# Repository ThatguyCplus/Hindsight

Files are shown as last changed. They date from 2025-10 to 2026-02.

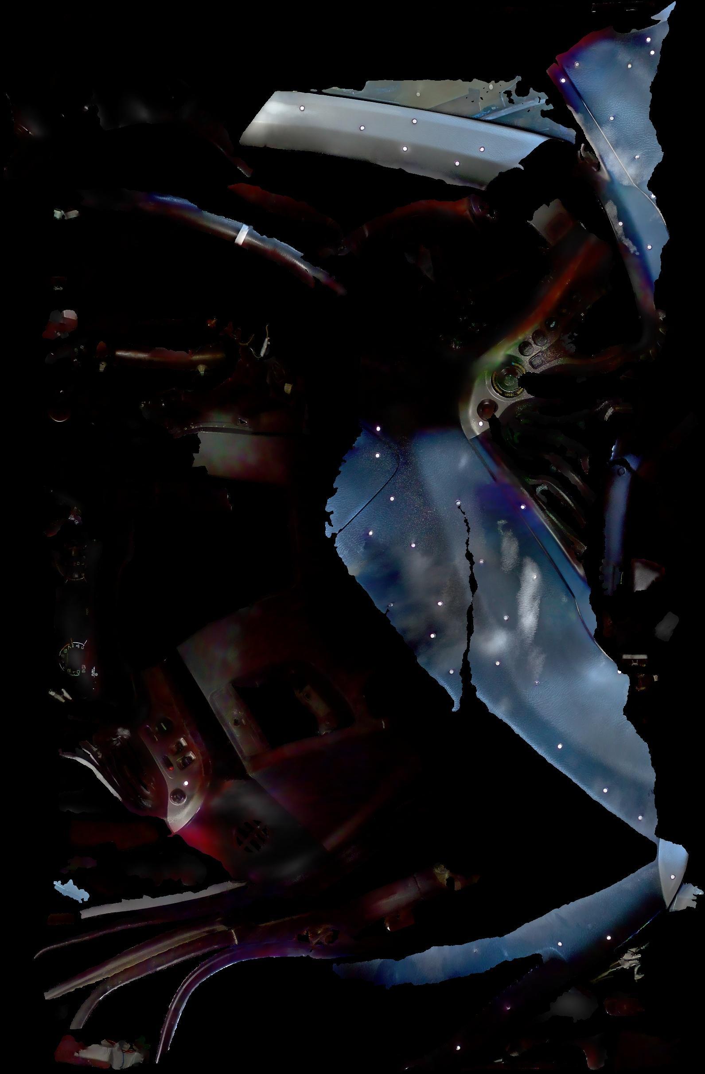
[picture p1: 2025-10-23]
Honda Insight 2002 3D scans/Dashboard/dashboardholesfilled.jpg

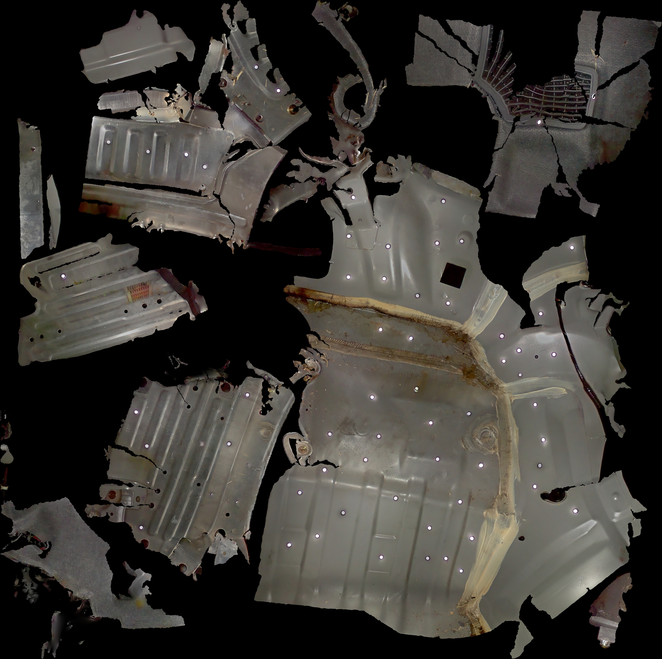
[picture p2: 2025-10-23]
Honda Insight 2002 3D scans/Insight behind trunk emtpy space/trunkemptyspace2002hondainsight2002scan.jpg

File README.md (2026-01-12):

# Hindsight

**Senior Design Project**: Build a safe, paraplegic-focused electronic throttle and brake control system for a 2002 Honda Insight. We’re designing the driver interface, selecting and validating sensors and actuators, and integrating everything on the vehicle for a live demo that aligns with SAE safety principles and ADA usability goals.usability goals.

## Project Overview

Hindsight retrofits a 2002 Honda Insight with an electronic throttle-and-brake assist system so paraplegic drivers can control the car using alternative hand inputs—without taking away the original pedals for other family members. It converts pedal commands into a safe, intuitive electronic interface while prioritizing fail-safes, manual override, and everyday usability for all drivers.

## Repository Structure

### 📂 Brakes/
Contains the brake control system implementation using a Tesla Gen2 iBooster unit.

<!-- TODO: Add image of iBooster installation in vehicle brake system -->
<!-- <img width="800" alt="iBooster Installation" src="path/to/ibooster-installation.jpg" /> -->


- **`Iboostercontrolnotworkingjustthrottlepostion/`**
  - `Iboostercontrolnotworkingjustthrottlepostion.ino` - Tesla Gen2 iBooster CAN bus controller
    - Controls brake system via CAN bus (500 kbps)
    - Uses MCP2515 CAN transceiver with Arduino Mega
    - Implements serial commands for brake control (apply/release/hold)
    - Monitors brake rod position and status via 0x39D CAN messages

https://github.com/user-attachments/assets/6a48c70b-f8df-4b89-a8cc-46501188acb3

- **`Adaptor CAD`**

  

<!-- TODO: Add image of brake control CAN bus setup or wiring diagram -->
<!-- <img width="800" alt="CAN Bus Wiring" src="path/to/can-bus-wiring.jpg" /> -->

### 📂 Throttle/
Complete throttle control system with Arduino firmware and mechanical CAD designs.

<!-- TODO: Add image of throttle mechanism with motor actuator and sensor -->
<!-- <img width="800" alt="Throttle Actuator System" src="path/to/throttle-actuator.jpg" /> -->
https://github.com/user-attachments/assets/ef57e486-5c61-4791-867c-b409ffe35655

#### **Throttle Arduino Sketches/**
Arduino firmware for throttle control and sensor testing:

- **`as5048atestingscketches/livereadout/`**
  - `livereadout.ino` - AS5048A magnetic angle sensor testing with motor control
    - Logs angle measurements at 100 Hz during motor cycles
    - Tests IBT-2/BTS7960 motor driver with forward/reverse/coast sequences
    - CSV output format for data analysis

- **`initialjoystick/`**
  - `initialjoystick.ino` - Joystick-based throttle control interface
    - Maps joystick input to motor control with exponential response curve
    - Implements hard-stop (electronic brake) with current monitoring
    - Safety features: dead zone, current limits, relay control

- **`Intialtestingcruisecontrolhindsight/`**
  - `Intialtestingcruisecontrolhindsight.ino` - Cruise control functionality testing
    - Initial implementation for throttle position holding

#### **Throttle CAD work/**
Mechanical design files for sensor mounting and bracket systems:



- Holds Diametric Magnet for sensor
  


- Sensor support bracket designs (v2, v3, v5)
- Files in multiple formats: `.SLDPRT` (SolidWorks), `.STL`, `.3MF`
- Key components:
  - `SensorSupportbracketv5covered.STL/.3MF` - Latest sensor mount design
  - `NoarmCC.SLDPRT` - Cruise control bracket without arm
  - `IntialCCbracket.SLDPRT` - Initial cruise control bracket concept

<!-- TODO: Add rendered image of CAD bracket designs or 3D printed parts -->
<!-- <img width="800" alt="Sensor Support Bracket v5" src="path/to/bracket-v5.jpg" /> -->
<!-- <img width="800" alt="3D Printed Bracket Installed" src="path/to/bracket-installed.jpg" /> -->

### 📂 Honda Insight 2002 3D scans/
3D scanned models of vehicle interior components used for design and integration.

<!-- TODO: Add example 3D scan visualization showing brake system context -->
<!-- <img width="800" alt="3D Scan - Brake System Context" src="path/to/brake-scan-view.jpg" /> -->



- **Brakes/**
  - iBooster context scans with corrected axis
  - Full detail scans of brake system mounting area
  - Formats: `.obj`, `.mtl`, `.SLDPRT`



- **Dashboard/**
  - Dashboard assembly with left interior pillar trim
  - Used for HMI (Human-Machine Interface) placement and integration



- **Footwell/**
  - Footwell area scans with trims installed
  - Critical for understanding pedal replacement constraints and mounting locations



- **Insight behind trunk empty space/**
  - Trunk empty space scans for component placement
  - Potential location for 12V battery relocation



- **UI (Between two seats parking brake area)/**
  - Area between seats where parking brake is located
  - Candidate location for alternative control interface placement
 


- **Leftwheelwellclutchmastercyclinderarea**
  - Wheel well area where the clutch master cylinder is on manual versions of the car
  - Candidate location for throttle actuator 

<!-- TODO: Add image of footwell area or dashboard showing integration points -->
<!-- <img width="800" alt="Footwell Integration" src="path/to/footwell-integration.jpg" /> -->
<!-- <img width="800" alt="UI Control Location" src="path/to/ui-location.jpg" /> -->

## Hardware Components

<!-- TODO: Add image of complete hardware setup or component layout diagram -->
<!-- <img width="800" alt="Hardware Component Layout" src="path/to/hardware-layout.jpg" /> -->

### Control Electronics
- **Arduino Mega 2560** - Primary microcontroller
- **MCP2515** - CAN bus controller (for brake system communication)
- **AS5048A** - Magnetic angle position sensor (for throttle position feedback)

### Actuators & Drivers
- **IBT-2 / BTS7960** - High-current H-bridge motor driver for throttle actuation
- **Tesla Gen2 iBooster** - Electronic brake booster (controlled via CAN bus)

### Sensors & Input
- **Analog Joystick** - Primary user input interface
- **Current Sense Resistors** - Motor current monitoring for safety

<!-- TODO: Add image of joystick interface or user control panel -->
<!-- <img width="800" alt="Joystick Control Interface" src="path/to/joystick-interface.jpg" /> -->

## Safety Features

- Current monitoring with automatic shutdown on overcurrent
- Hard-stop (electronic brake) functionality for rapid motor stopping
- CAN bus status monitoring for brake system feedback
- Exponential response curves for smooth control input
- Dead zone implementation to prevent unintended operation

## Software Requirements

- Arduino IDE (for firmware development)
- SolidWorks (for CAD file viewing/editing - `.SLDPRT` files)
- 3D viewer/printing software (for `.STL`, `.3MF` files)
- CAN bus analysis tools (optional, for debugging)

## Getting Started

1. **Hardware Setup**: Review the wiring diagrams in the Arduino sketch comments
2. **Firmware**: Upload the appropriate sketch to your Arduino Mega
3. **Calibration**: Adjust tuning parameters in the firmware (dead zones, current limits, etc.)
4. **Testing**: Use serial monitor for debugging and status monitoring

<!-- TODO: Add wiring diagram or connection schematic -->
<!-- <img width="800" alt="System Wiring Diagram" src="path/to/wiring-diagram.jpg" /> -->

## Serial Commands (Brake System)

When using the iBooster controller (`Iboostercontrolnotworkingjustthrottlepostion.ino`):

- `r` - Toggle raw CAN log
- `e` - Enable external request (take control)
- `d` - Disable external request (driver only, flow to zero-point)
- `b` - Apply brakes (flow_rate > zero point)
- `s` - Release brakes (flow_rate < zero point)
- `z` - Hold pressure (flow_rate = zero point)

## License

This project is licensed under the GNU General Public License v3.0 - see the [LICENSE](LICENSE) file for details.

## Contributing

This is a senior design project. For questions or contributions, please open an issue or contact the project maintainers.

---

## ⚠️ Important Disclaimer

**RESEARCH PROJECT ONLY — NOT FOR PRODUCTION USE**

This project is an academic research and development effort conducted as part of a senior design course. It is intended **solely for educational, research, and demonstration purposes**.

**NO WARRANTIES**: This software, hardware designs, and documentation are provided "AS IS" without warranty of any kind, express or implied, including but not limited to warranties of merchantability, fitness for a particular purpose, or safety for road use.

**NOT INTENDED FOR PUBLIC ROAD USE**: 
- This system modifies critical vehicle safety systems (throttle and brake controls)
- **DO NOT install, test, or operate this system on public roads**
- This system has NOT been certified, validated, or approved for real-world vehicle operation
- Any use of this system is at your own risk

**RESPONSIBILITY**: Anyone using, modifying, or building upon this project assumes full responsibility and liability for any damages, injuries, or legal consequences that may result. The authors and contributors are not responsible for any outcomes resulting from the use of this research project.

**FOR RESEARCH AND EDUCATIONAL PURPOSES ONLY.**

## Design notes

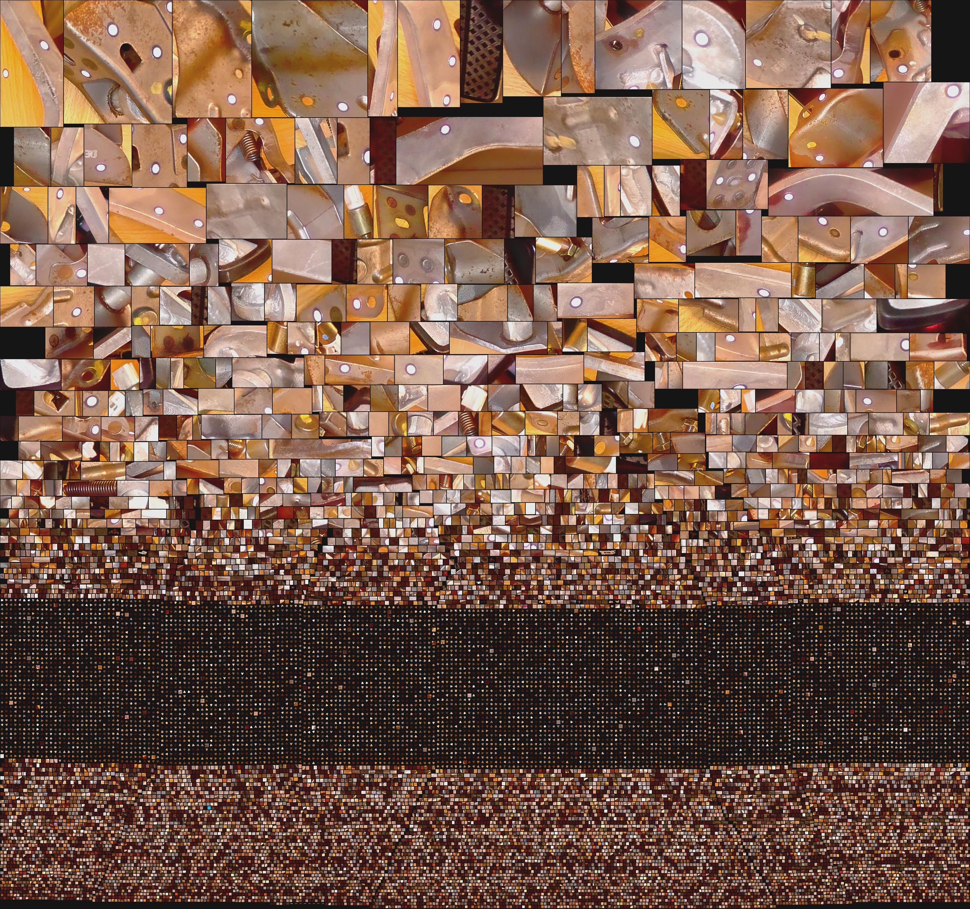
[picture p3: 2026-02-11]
Honda Insight 2002 3D scans/BrakePedalandbracket/optimizedscanbrakepedal.jpg

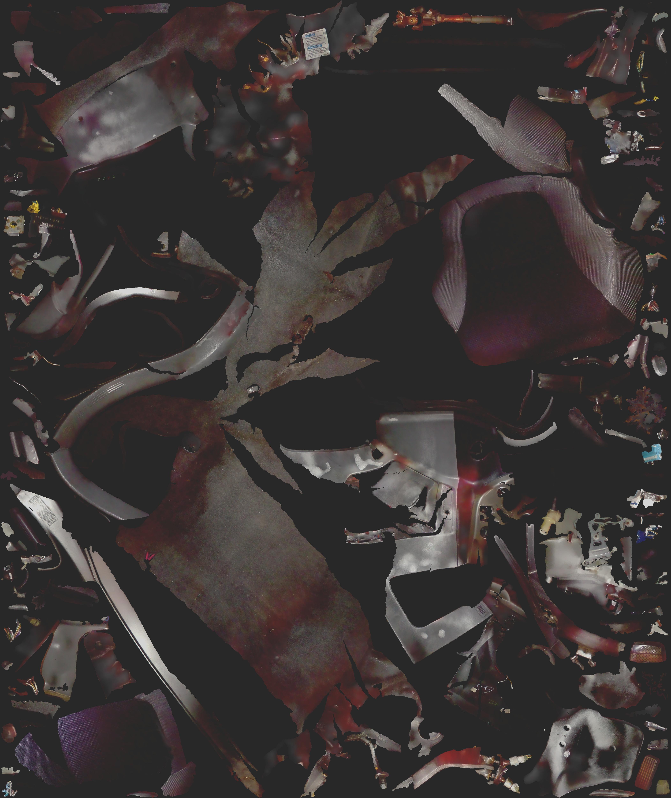
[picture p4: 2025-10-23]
Honda Insight 2002 3D scans/Footwell/footwell.jpg

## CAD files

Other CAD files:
Throttle/Throttle CAD work/Assem1.SLDASM
Honda Insight 2002 3D scans/Brakes/fulldetailIboostercontextscan.obj
Brakes/AdaptorCAD/BrakeboosterAdapterV1.1/HondatoTeslaAdapter.SLDASM
Brakes/AdaptorCAD/BrakeboosterAdapterV1.1/adapterplate1teslaside.SLDPRT
Brakes/AdaptorCAD/iboosterrodextension/theadaptorplasticfornow.SLDPRT
Honda Insight 2002 3D scans/BrakePedalandbracket/2milfacesbrakepedal.obj
Honda Insight 2002 3D scans/Brakes/iboostercontext.SLDPRT
Honda Insight 2002 3D scans/Dashboard/Dahsboardholesfilledwithleftinteriorpillartrim.obj
Honda Insight 2002 3D scans/Footwell/Footwellwithtrimsinstalled.SLDPRT
Honda Insight 2002 3D scans/Insight behind trunk emtpy space/trunkemptyspace2002hondainsight2002scan.obj
Honda Insight 2002 3D scans/UI ( Between two seats parking brake area)/UIbetweenseatsparkingbrakenocoverHondaInsight2002cleaned.obj
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

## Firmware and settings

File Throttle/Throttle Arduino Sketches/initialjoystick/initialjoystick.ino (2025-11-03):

// Joystick → IBT-2 (BTS7960) with HARD STOP + clean current table
// Mega pins: REN=30, LEN=31, RPWM=44, LPWM=45, Relay=22, VRy=A2, SW=D23, R_IS=A0, L_IS=A1
#include <math.h>

#define RELAY_PIN 22
#define REN_PIN   30
#define LEN_PIN   31
#define RPWM_PIN  44
#define LPWM_PIN  45
#define JOY_Y_PIN A2
#define JOY_SW_PIN 23
#define RIS_PIN   A0
#define LIS_PIN   A1

// ----- Tuning -----
const uint8_t MAX_DUTY   = 230;   // cap speed at ends (0..255)
const uint8_t MIN_MOVE   = 70;    // min duty to overcome stiction
const int     DEAD_BAND  = 40;    // joystick dead zone around center
const float   EXPO       = 2.8;   // slow middle, fast ends (1.0 = linear)
const uint8_t SLEW_STEP  = 12;    // bigger step = snappier response
const uint16_t LOOP_MS   = 10;    // control loop rate

// Hard-stop (electronic brake) parameters
const uint16_t BRAKE_MS  = 120;   // how long to apply brake on stop
const float    BRAKE_I_MAX = 25.0; // abort brake if total current exceeds this

// Current-sense calibration (tune with clamp meter)
const float ADC_VREF   = 5.0;
const float AMPS_PER_V = 10.0;
const int   AVG_IS     = 6;
const int   AVG_JOY    = 8;

// Button behavior
const bool TOGGLE_MODE = true;    // true: press to latch relay; false: hold-to-run

// ----- Internals -----
int  joyCenter = 512;
int  cmdPWM = 0;                  // signed -255..+255
bool relayEnabled = false;
bool lastBtn = false;
unsigned long lastPrint = 0;
int  printCount = 0;

int readAvg(uint8_t pin, int n){ long acc=0; for(int i=0;i<n;i++) acc+=analogRead(pin); return acc/n; }
float readV(uint8_t pin){ long acc=0; for(int i=0;i<AVG_IS;i++) acc+=analogRead(pin); return (acc/float(AVG_IS))*(ADC_VREF/1023.0f); }

void driveMotorSigned(int val){
  val = constrain(val, -255, 255);
  if (val > 0){ analogWrite(RPWM_PIN, val); analogWrite(LPWM_PIN, 0); }
  else if (val < 0){ analogWrite(RPWM_PIN, 0); analogWrite(LPWM_PIN, -val); }
  else { analogWrite(RPWM_PIN, 0); analogWrite(LPWM_PIN, 0); }
}

// brief electronic brake, with current safety
void hardStop(){
  // apply brake (both PWMs high) but bail if current spikes too high
  unsigned long t0 = millis();
  analogWrite(RPWM_PIN, 255);
  analogWrite(LPWM_PIN, 255);
  while (millis() - t0 < BRAKE_MS){
    float iTot = (readV(RIS_PIN) + readV(LIS_PIN)) * AMPS_PER_V;
    if (iTot > BRAKE_I_MAX) break;
  }
  // release to zero
  analogWrite(RPWM_PIN, 0);
  analogWrite(LPWM_PIN, 0);
  cmdPWM = 0;
}

int mapExpoSigned(int centered){
  if (abs(centered) < DEAD_BAND) return 0;
  float span = 512.0f - DEAD_BAND;
  float sgn  = (centered > 0) ? 1.0f : -1.0f;
  float mag  = fminf(1.0f, fabsf(centered) / span);
  float shaped = powf(mag, EXPO);
  int duty = (int)roundf(shaped * MAX_DUTY);
  if (duty > 0 && duty < MIN_MOVE) duty = MIN_MOVE;
  return (int)(sgn * duty);
}

void setup(){
  Serial.begin(9600);
  pinMode(RELAY_PIN, OUTPUT); digitalWrite(RELAY_PIN, LOW);
  pinMode(REN_PIN, OUTPUT);   digitalWrite(REN_PIN, HIGH);
  pinMode(LEN_PIN, OUTPUT);   digitalWrite(LEN_PIN, HIGH);
  pinMode(RPWM_PIN, OUTPUT);  analogWrite(RPWM_PIN, 0);
  pinMode(LPWM_PIN, OUTPUT);  analogWrite(LPWM_PIN, 0);
  pinMode(JOY_SW_PIN, INPUT_PULLUP);

  delay(100);
  joyCenter = readAvg(JOY_Y_PIN, 48);

  // print header
  Serial.println(F("rawY  cent  targ  cmd   IR[A]  IL[A]  ITot  DIR  REL"));
}

void loop(){
  // --- button → relay state ---
  bool btn = (digitalRead(JOY_SW_PIN) == LOW);
  if (TOGGLE_MODE){
    if (btn && !lastBtn) relayEnabled = !relayEnabled;
  } else {
    relayEnabled = btn;
  }
  lastBtn = btn;
  digitalWrite(RELAY_PIN, relayEnabled ? HIGH : LOW);

  // --- joystick to target ---
  int raw = readAvg(JOY_Y_PIN, AVG_JOY);
  int centered = raw - joyCenter;
  int target = relayEnabled ? mapExpoSigned(centered) : 0;

  // If we just entered "stop" state, perform hard stop
  static bool wasMoving = false;
  bool isMovingCmd = (target != 0);
  if (!isMovingCmd && wasMoving){
    hardStop();
  }
  wasMoving = isMovingCmd;

  // Slew to target (snappier thanks to larger SLEW_STEP)
  if (cmdPWM < target) cmdPWM = min(cmdPWM + SLEW_STEP, target);
  else if (cmdPWM > target) cmdPWM = max(cmdPWM - SLEW_STEP, target);

  // If relay is off, force stop
  if (!relayEnabled){
    if (cmdPWM != 0) hardStop();
    cmdPWM = 0;
  }

  // Drive motor
  driveMotorSigned(cmdPWM);

  // Telemetry (10 Hz) with header refresh every ~30 lines
  unsigned long now = millis();
  if (now - lastPrint >= 100){
    float vR = readV(RIS_PIN), vL = readV(LIS_PIN);
    float iR = vR * AMPS_PER_V, iL = vL * AMPS_PER_V;
    float iTot = iR + iL;
    const char* dir = (cmdPWM>0) ? "FWD" : (cmdPWM<0) ? "REV" : "----";
    const char* rel = relayEnabled ? "ON " : "OFF";

    // fixed-width-ish table
    char buf[120];
    snprintf(buf, sizeof(buf), "%4d %5d %5d %5d  %5.2f  %5.2f  %5.2f  %4s  %3s",
             raw, centered, target, cmdPWM, iR, iL, iTot, dir, rel);
    Serial.println(buf);

    printCount++;
    if (printCount >= 30){
      Serial.println(F("rawY  cent  targ  cmd   IR[A]  IL[A]  ITot  DIR  REL"));
      printCount = 0;
    }
    lastPrint = now;
  }

  delay(LOOP_MS);
}

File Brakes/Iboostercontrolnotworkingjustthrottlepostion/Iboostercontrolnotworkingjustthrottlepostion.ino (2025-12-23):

/*
 * Tesla Gen2 iBooster Controller (Yaw CAN only)
 * Hardware:
 *   - Arduino Mega
 *   - MCP2515 + transceiver on Yaw CAN (500 kbps)
 *   - MCP2515 crystal: set MCP_CLOCK below (MCP_8MHZ or MCP_16MHZ)
 *
 * Wiring (Mega):
 *   SCK  -> 52
 *   MOSI -> 51
 *   MISO -> 50
 *   CS   -> 4   (change CS_PIN below if needed)
 *   INT  -> not used (polling)
 *   VCC  -> 5V, GND -> GND
 *
 * Serial commands (115200 baud):
 *   r : toggle raw CAN log
 *   e : enable external request (take control)
 *   d : disable external request (driver only, flow to zero-point)
 *   b : apply brakes   (flow_rate > zero point)
 *   s : release brakes (flow_rate < zero point)
 *   z : hold pressure  (flow_rate = zero point)
 */

#include <SPI.h>
#include <mcp2515.h>

// ---------- Config ----------
#define CS_PIN        4
#define CAN_SPEED     CAN_500KBPS
#define MCP_CLOCK     MCP_8MHZ    // change to MCP_16MHZ if your MCP2515 is 16 MHz

// IDs (Yaw CAN)
#define ID_VEHICLE_STATUS  0x38B  // BO_ 907
#define ID_BRAKE_REQUEST   0x38C  // BO_ 908
#define ID_VEHICLE_ALIVE   0x38D  // BO_ 909
#define ID_STATUS          0x39D  // BO_ 925

// Timing
#define TX_PERIOD_MS       10
#define DASH_PERIOD_MS     500

// Flow rate
#define FLOW_ZERO          0x7E00  // 32256
#define FLOW_RANGE         5120    // +/- span for quick apply/release

// CRC8 SAE J1850
#define CRC_POLY   0x1D
#define CRC_INIT   0xFF
#define CRC_XOROUT 0xFF

MCP2515 yawCAN(CS_PIN);
uint8_t crc8_lut[256];

// Counters
uint8_t vs_ctr = 0, br_ctr = 0, va_ctr = 0;

// Control state
bool external_request = false;
uint16_t flow_rate = FLOW_ZERO;

// Status (0x39D)
float rod_pos_mm = 0.0f;
uint8_t stat_status = 0;
uint8_t stat_internal = 0;
uint8_t stat_driver = 0;
uint8_t stat_counter = 0;
bool stat_crc_ok = false;
unsigned long stat_age_ms = 0;

// Logging
bool raw_log = false;

// Timing
unsigned long last_tx = 0;
unsigned long last_dash = 0;
unsigned long t0 = 0;

// ---------- CRC ----------
void gen_crc8() {
  for (uint16_t i = 0; i < 256; i++) {
    uint8_t c = i;
    for (uint8_t b = 0; b < 8; b++) c = (c & 0x80) ? (uint8_t)((c << 1) ^ CRC_POLY) : (uint8_t)(c << 1);
    crc8_lut[i] = c;
  }
}
uint8_t crc8(const uint8_t *d, int len) {
  uint8_t c = CRC_INIT;
  for (int i = 1; i < len; i++) {
    c ^= d[i];
    c = crc8_lut[c];
  }
  return c ^ CRC_XOROUT;
}

// ---------- TX frames ----------
void send_38B() {
  struct can_frame m;
  m.can_id = ID_VEHICLE_STATUS;
  m.can_dlc = 4;
  uint8_t *d = m.data;
  d[0] = 0;
  d[1] = (vs_ctr & 0x0F);
  if (external_request) d[1] |= 0x40;  // external_brake_request bit
  d[2] = 0x05; // unknown3 low
  d[3] = 0x00; // unknown3 high
  d[0] = crc8(d, 4);
  yawCAN.sendMessage(&m);
  vs_ctr = (vs_ctr + 1) & 0x0F;
}

void send_38C() {
  struct can_frame m;
  m.can_id = ID_BRAKE_REQUEST;
  m.can_dlc = 4;
  uint8_t *d = m.data;
  d[0] = 0;
  d[1] = (br_ctr & 0x0F);
  if (external_request) d[1] |= 0x40;  // external_request bit
  d[2] = (uint8_t)(flow_rate & 0xFF);
  d[3] = (uint8_t)((flow_rate >> 8) & 0xFF);
  d[0] = crc8(d, 4);
  yawCAN.sendMessage(&m);
  br_ctr = (br_ctr + 1) & 0x0F;
}

void send_38D() {
  struct can_frame m;
  m.can_id = ID_VEHICLE_ALIVE;
  m.can_dlc = 4;
  uint8_t *d = m.data;
  d[0] = 0;
  d[1] = (va_ctr & 0x0F); // counter
  d[2] = 0x47;            // known working value
  d[3] = 0x00;
  d[0] = crc8(d, 4);
  yawCAN.sendMessage(&m);
  va_ctr = (va_ctr + 1) & 0x0F;
}

// ---------- RX parsing 0x39D ----------
void parse_39D(const struct can_frame &m) {
  const uint8_t *d = m.data;
  uint8_t c = crc8(d, m.can_dlc);
  stat_crc_ok = (c == d[0]);
  stat_counter = d[1] & 0x0F;

  // Approx decode per DBC (21|12, scale 0.015625, offset -5)
  uint16_t raw12 = (uint16_t)d[2] | ((uint16_t)d[3] << 8);
  rod_pos_mm = raw12 * 0.015625f - 5.0f;

  stat_status       = (d[1] >> 4) & 0x07;     // (12|3) approx
  stat_driver       = d[2] & 0x03;            // (16|2)
  stat_internal     = (d[2] >> 2) & 0x07;     // (18|3)
  stat_age_ms = millis();
}

// ---------- Process RX ----------
void poll_rx() {
  struct can_frame m;
  if (yawCAN.readMessage(&m) == MCP2515::ERROR_OK) {
    uint16_t id = m.can_id & 0x7FF;
    if (raw_log) {
      Serial.print("YCAN "); Serial.print(id, HEX);
      Serial.print(" ["); Serial.print(m.can_dlc); Serial.print("] ");
      for (uint8_t i = 0; i < m.can_dlc; i++) {
        if (m.data[i] < 0x10) Serial.print('0');
        Serial.print(m.data[i], HEX); Serial.print(' ');
      }
      Serial.println();
    }
    if (id == ID_STATUS && m.can_dlc >= 4) parse_39D(m);
  }
}

// ---------- Serial commands ----------
void handle_cmd() {
  if (!Serial.available()) return;
  char c = Serial.read();
  switch (c) {
    case 'r': case 'R':
      raw_log = !raw_log;
      Serial.print("Raw log: "); Serial.println(raw_log ? "ON" : "OFF");
      break;
    case 'e': case 'E':
      external_request = true;
      Serial.println("External request ENABLED");
      break;
    case 'd': case 'D':
      external_request = false;
      flow_rate = FLOW_ZERO;
      Serial.println("External request DISABLED, flow=zero");
      break;
    case 'b': case 'B':
      external_request = true;
      flow_rate = FLOW_ZERO + (FLOW_RANGE / 2);
      Serial.print("Brake APPLY, flow="); Serial.println(flow_rate);
      break;
    case 's': case 'S':
      external_request = true;
      flow_rate = FLOW_ZERO - (FLOW_RANGE / 2);
      Serial.print("Brake RELEASE, flow="); Serial.println(flow_rate);
      break;
    case 'z': case 'Z':
      external_request = true;
      flow_rate = FLOW_ZERO;
      Serial.println("Brake HOLD (zero)");
      break;
    default: break;
  }
  while (Serial.available()) Serial.read(); // flush
}

// ---------- Dashboard ----------
void dash() {
  Serial.println("=== Gen2 iBooster Yaw Controller ===");
  Serial.print("t = "); Serial.print((millis() - t0) / 1000); Serial.println(" s");

  Serial.print("ext_request: "); Serial.println(external_request ? "ON" : "OFF");
  Serial.print("flow_rate  : "); Serial.println(flow_rate);

  Serial.println("Status 0x39D:");
  Serial.print("  rod_pos(mm): "); Serial.println(rod_pos_mm, 2);
  Serial.print("  status     : "); Serial.println(stat_status);
  Serial.print("  internal   : "); Serial.println(stat_internal);
  Serial.print("  drv_brake  : "); Serial.println(stat_driver);
  Serial.print("  counter    : "); Serial.println(stat_counter);
  Serial.print("  CRC        : "); Serial.println(stat_crc_ok ? "OK" : "FAIL/no data");
  Serial.print("  age (ms)   : ");
  if (stat_age_ms == 0) Serial.println("no frame"); else Serial.println(millis() - stat_age_ms);

  Serial.println("Commands: r raw | e enable | d disable | b apply | s release | z hold");
  Serial.println();
}
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

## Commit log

2025-10-22 Track SLDPRT/3mf/ply via Git LFS
2025-10-23 3d scans
    [Dahsboardholesfilledwithleftinteriorpillartrim.obj, Footwellwithtrimsinstalled.obj, UIbetweenseatsparkingbrakenocoverHondaInsight2002cleaned.obj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]
2025-11-03 Joystick control for cruise control actuator
2025-11-13 cruise controller 3d scans
    3d scans of the controller
    [02mmccroughscannoarm.obj, LITTLEWHEELROUGH.obj, cceverythingetc.3mf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]
2025-11-20 Brakeboosternobrakeboosterfitmentcheckscan
    uploaded a 3d scan that has no brake booster to properly clock the adapter plate
    [BrakesnoboostercorrectedAxis(usethisone).obj]
2025-11-23 Brakeboosterremoved
    Brakeboosterremoved
    [SensorSupportbracketv2.3mf, SensorSupportbracketv2.SLDPRT, SensorSupportbracketv2.STL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]
2025-12-23 updates
    upgrades people upgrades
    [SensorSupportbracketv2.SLDPRT, SensorSupportbracketv3.SLDPRT, SensorSupportbracketv5covered.3mf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]
2025-12-26 hg09
    y980
    [simplified1mill.obj, simplified200000faces.obj]
2026-01-09 new rev of files
    hit bandwith trying to uplaod all new rev
    [Footwellwithtrimsinstalled.SLDPRT, iboostercontext.SLDPRT]
2026-01-10 Track STL and MIX with Git LFS
2026-01-10 testing why git is mad
    ignore
    [SensorSupportbracketv2.STL, SensorSupportbracketv5covered.STL]
2026-01-10 Organizing
    Rearranged the structure so it's easier to understand
    [02mmccroughscannoarm.SLDPRT, BrakesnoboostercorrectedAxis(usethisone).obj, Dahsboardholesfilledwithleftinteriorpillartrim.obj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]
2026-01-11 Update README with images and additional details
    Added images for iBooster installation, brake control CAN bus setup, throttle actuator system, and various scans related to the brake system and interior layout.
2026-01-12 Update README with left wheel well details
    Added description for left wheel well clutch master cylinder area.
2026-01-12 added wheelscan zip
    added wheelscan zip
2026-01-12 Track SolidWorks assemblies/drawings/parts in LFS
2026-01-12 AdapterCadV1
    CAD for Ibooster CAD within the 2002 Honda Insight
    [HondatoTeslaAdapter.SLDASM, V1.190331A552_High-Strength Steel Coupling Nut.SLDPRT, V1.191263A476_Zinc-Plated Alloy Steel Hex Drive Flat Head Screw.SLDPRT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]
2026-01-12 Update README with Adaptor CAD image and Throttle CAD details
    Added an image for the Adaptor CAD section and updated the Throttle CAD work section.
2026-01-12 Enhance README with CAD work details and images
    Added images and details for sensor mounting and bracket systems.
2026-01-12 added a few cad files
2026-01-17 added bezel
    bezelscans
    [Assem1.SLDASM, SensorSupportbracketv3.SLDPRT]
2026-01-30 added sldprtparts
    added solidworksfiles
    [adapterplate1teslaside.SLDPRT]
2026-02-04 cadadded
    cad
    [V1.1throughholesform8adn6screws.SLDPRT, adapterplate1teslaside.SLDPRT]
2026-02-05 cad drawings for adaptor
    [iboosterplatesv2.SLDDRW, insightsideplatev2.SLDDRW]
2026-02-11 brake pedal scans
    brakepedalobj
    [2milfacesbrakepedal.obj]
2026-02-20 yokeadaptor
    yoke
    [theadaptorplasticfornow.SLDPRT]
